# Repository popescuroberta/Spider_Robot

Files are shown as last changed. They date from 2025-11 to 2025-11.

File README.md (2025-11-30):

# 🕷️ Spider Robot – Assembly & Setup Guide

This repository contains the full instructions for assembling an Arduino-based spider robot with 8 servos, 3D-printed parts, and a DC-DC buck converter.  
Follow this guide carefully to ensure proper mechanical alignment and safe electrical wiring.

---

## 📦 Required Components

### Electronics
- Arduino Nano  
- Arduino Nano Expansion Shield  
- DC-DC Buck (Step-Down) Converter  
- 8 × SG90 / MG90 Servo Motors  
- Battery Pack

### Printed & Mechanical Parts
- Support Cross  
- Upper and Lower Servo Supports  
- Shoulder Elements (mirrored pairs)  
- Body Case and Top Plate  
- Claw Attachments  
- Printed Servo Support Caps

### Hardware
- M2 Nuts  
- M2 × 10 mm Screws  
- M2 × 8 mm Screws (for buck converter)  
- M3 Nuts  
- M3 × 6 mm Screws  
- M3 × 10 mm Screws  
- M3 Washers  
- Double-Sided Tape  
- Self-tapping screws (included with servos)

---

## 🛠️ Assembly Instructions

### 1. Assemble the Support Cross and Servo Shoulders
1. Insert **M2 nuts** into the grooves of the support cross.  
   - Align the nut with the screw hole.  
   - If needed, gently push the nut with a flat screwdriver.

2. Insert **M2 × 10 mm screws** through the servo support holes and tighten them into the nuts in the support cross.

3. Attach the remaining structural servo-support parts using **4 screws + 4 nuts (M2)**.

4. Assemble the **second shoulder as a mirrored version** of the first.  
   - Upper and lower supports must swap places in the mirrored part.

5. Assemble the second pair of shoulders similarly.  
   - You must end up with **two mirrored pairs**.

---

## 🔌 2. Connecting the Expansion Board & DC-DC Converter

You may solder these before or after mechanical assembly.

- Solder the buck converter **VOUT → 5V** and **GND → GND** to the expansion board.  
- Do **not** use standard male–female jumper wires (current ≈ 1A may overheat them).

### Wiring Polarity
- **Battery Pack → VIN & GND (buck input)**  
- **Expansion Board → VOUT & GND (buck output)**

After tightening terminal screws, lightly pull each wire to ensure it’s secure.

---

## 🧩 3. Installing the Printed Servo Supports

Using double-sided tape, attach each printed support to the *servo casing*:
- The cylindrical part of the support must be on the **shaft side**.
- Prepare all **8 servos** this way.

---

## 🎯 4. Servo Calibration (Zero Positioning)

All 8 servos must be set to **90°** before installation.

You can calibrate using:
- A servo tester, or  
- Calibration code on the Arduino.

### Servo wiring:
- **Red → 5V**  
- **Brown → GND**  
- **Orange → Signal**

Test any servo issues by trying a different signal pin.

Disconnect calibrated servos and set them aside.

---

## ⚙️ 5. Installing Servos Into the Shoulders

1. Insert calibrated servos into each shoulder assembly.  
2. If fitting is tight:
   - Loosen screws 1–2 mm.  
   - Retighten after the servo is fully inserted.

3. Test rotation of the cylindrical support inside the lower groove.  
   - If too stiff, rotate the joint several times to loosen it.

4. If the servo horn does not fully enter its slot:
   - Gently push it with pliers.

Use the **self-tapping screws** from the servo kit to secure horns and mounts.

---

## 🔋 6. Battery Compartment

Do **not** drill additional holes.  
Battery packs vary in shape and hole placement.

- Place the battery pack into the lower case, held by printed borders.  
- Use double-sided tape if needed.

---

## 🏗️ 7. Body Assembly & Electronics Placement

### Step 1 — Install Standoffs  
Use **M3 × 6 screws** and **M3 washers** to mount the standoffs to the body.

### Step 2 — Mount the Expansion Board  
Use:  
- **M3 × 10 screws**, **M3 nuts**, **M3 washers**  
- Mount using the two center holes (hard to access later).

### Step 3 — Mount the DC-DC Buck Converter  
Use:  
- **M2 × 8 screws**, washers, and M2 nuts

### Step 4 — Attach the Top Plate  
- **M3 × 10 screws** for holes below the expansion board  
- **M3 × 6 screws** for the other holes  
- Always place M3 washers on the plastic side.

Finally, insert the **Arduino Nano** into the expansion shield.

---

## 🕷️ 8. Final Assembly

- Insert the shoulder units into the case grooves.  
- Attach the claws to the servo shafts.  
- Secure all servo horns and claws using the included self-tapping screws.

---

## 🔗 9. Servo Port Mapping

- Shoulder servos → **Odd-numbered ports**  
- Claw servos → **Even-numbered ports**  
- Counting begins at the **4th pin**.

Orientation:
- **Front (head)** = side closer to the expansion board  
- **Tail** = side near the buck converter  
- Servos are numbered **clockwise** around the body.

---

## 🧪 10. Final Calibration (with Arduino Code)

Upload the calibration program:
- All servos return to a **zero position** at startup.  
- Check if all legs are perpendicular to the body.

If a leg is misaligned:
- Remove the servo horn  
- Reposition at 90°  
- Reattach

**Precision is important; even small errors affect walking performance.**

---

## ✔️ The Spider Robot Is Ready!

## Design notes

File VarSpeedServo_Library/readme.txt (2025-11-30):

To install the VarSpeedServo library in Arduino IDE, you need to follow these steps:
1. Download the .zip archive
2. After downloading, reopen Arduino IDE. In the menu Sketch -> Include library -> Add .zip library...
3. From the dialog box, select the archive you downloaded
4. To verify the functionality, restart Arduino IDE. Compile and upload a test code to an Arduino board. If there are no errors, everything is fine

Advantages of using the VarSpeedServo library:
1. Allows simultaneous use of up to 8 asynchronous servomotors
2. The speed of the servomotors can be set (an advantage, because we can avoid overloading the Arduino board)
3. Multiple commands can be sent simultaneously to the servomotor, without overloading it

Recommendation: move the library archive to the folder intended for the IDE application, so that, in case of deletion from the save folder, possible errors can be avoided.

https://github.com/netlabtoolkit/VarSpeedServo

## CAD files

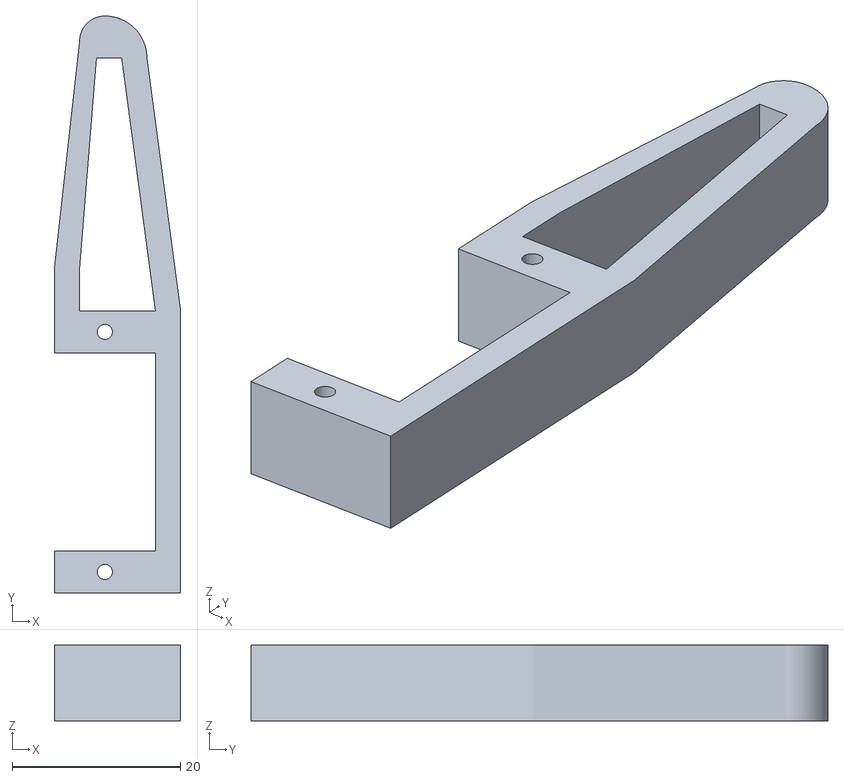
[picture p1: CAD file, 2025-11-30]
Files_For_Printing/Claw.stl
15.0 x 68.5 x 9.00

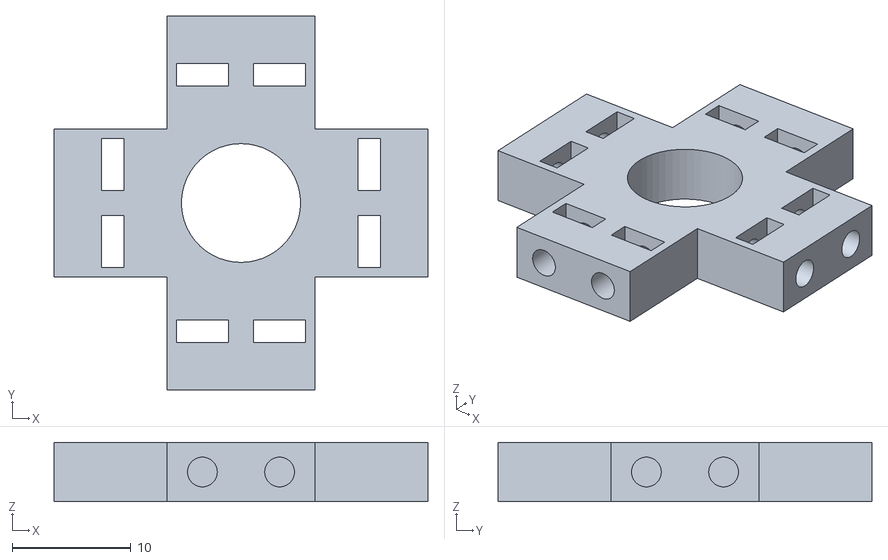
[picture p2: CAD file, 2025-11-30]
Files_For_Printing/Support cross.stl
31.5 x 31.5 x 5.00

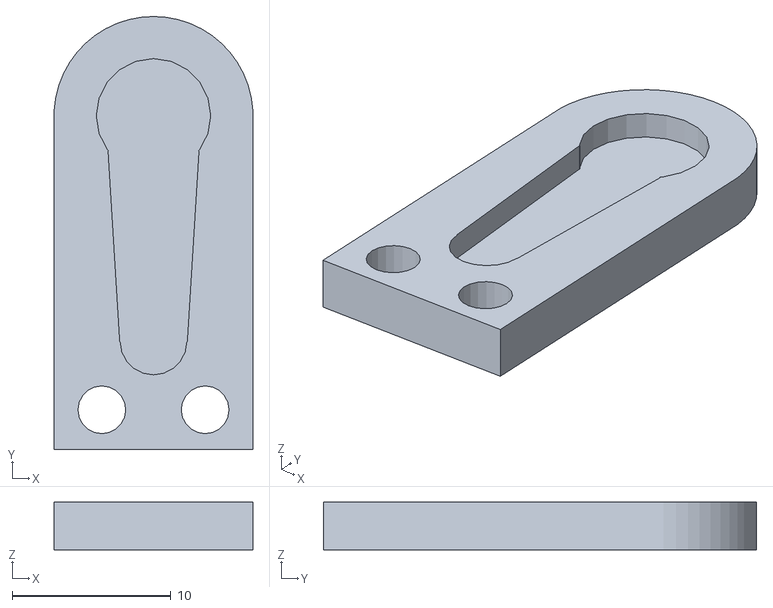
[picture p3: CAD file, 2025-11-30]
Files_For_Printing/Upper servo support.stl
12.5 x 27.2 x 3.00

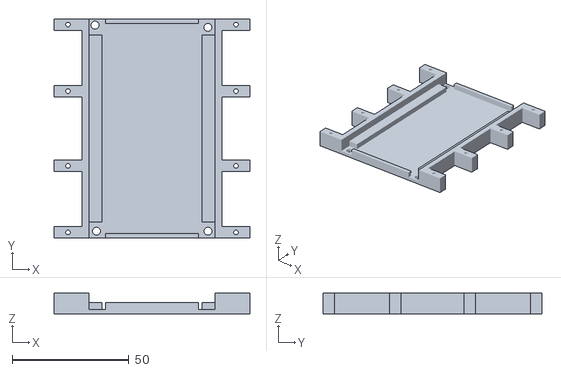
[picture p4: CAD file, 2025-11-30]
Files_For_Printing/Case (body).stl
84.0 x 94.0 x 9.00

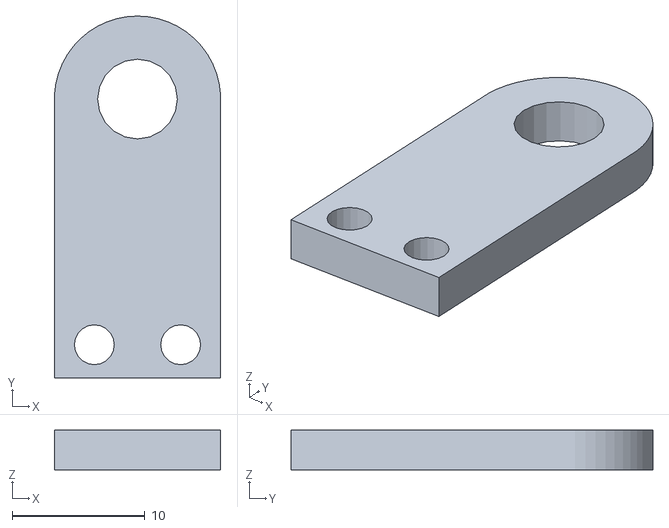
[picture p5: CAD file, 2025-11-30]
Files_For_Printing/Lower servo support.stl
12.5 x 27.2 x 3.00

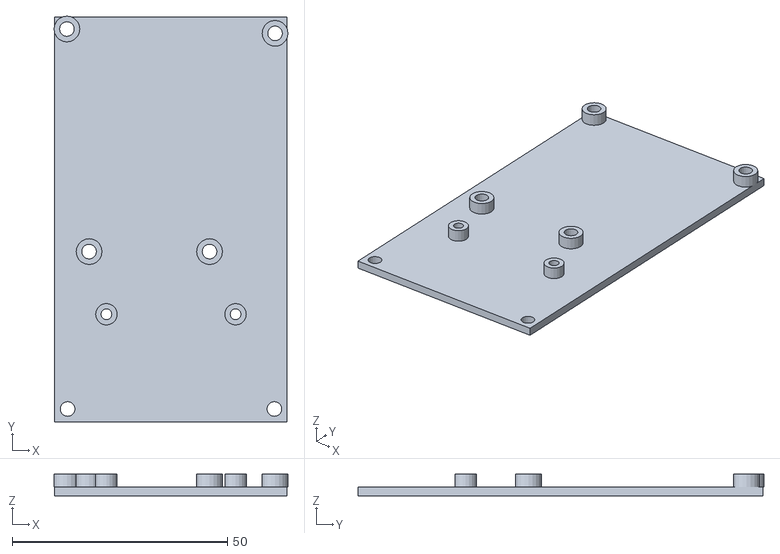
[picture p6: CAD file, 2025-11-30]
Files_For_Printing/Plate.stl
54.4 x 94.2 x 5.00

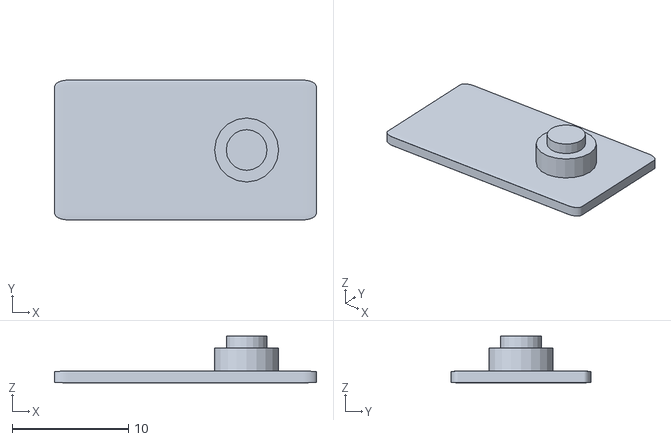
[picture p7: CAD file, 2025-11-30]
Files_For_Printing/Servo support.stl
22.5 x 12.0 x 4.00

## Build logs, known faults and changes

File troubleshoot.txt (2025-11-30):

A. The code does not work
Check the library used. If the VarSpeedServo library is used, in the Code folder, there is a readme with the steps to load the library

B. Although the motors were adjusted before assembly to 90 degrees, once assembled, they seem to go in the wrong direction
It is about the way the shoulder is attached. The shoulder where the clamp and the servo are attached to the body will be removed, and the shoulder components (the one with the incision for the servo arm and the one for rotating) can be reversed. Afterwards, check the servo motor again if it rotates in the correct direction. Most of the time, this operation solves the problem

C. The code does not load on my Arduino, although I have the library installed in the IDE
Most of the time, it is from the processor that the application has. In the Tools -> Processor -> ATmega 328P (Old Bootloader) tab, it will solve the problem. Chinese motherboards have, in 80% of cases, this processor

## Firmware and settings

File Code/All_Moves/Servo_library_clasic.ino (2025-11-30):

#include <Servo.h>

// Declarație servomotoare
Servo myServo4;
Servo myServo5;
Servo myServo6;
Servo myServo7;
Servo myServo8;
Servo myServo9;
Servo myServo10;
Servo myServo11;

void setup() {
  // Inițializare servomotoare
  myServo4.attach(4);
  myServo5.attach(5);
  myServo6.attach(6);
  myServo7.attach(7);
  myServo8.attach(8);
  myServo9.attach(9);
  myServo10.attach(10);
  myServo11.attach(11);
  
  // Pornire din poziția inițială
  startPosition();
  delay(5000); // Așteptare inițială
}

void loop() {
  // Secvență de mișcări
  walkForward();
  delay(1000);
  
  turnLeft();
  delay(1000);
  
  turnRight();
  delay(1000);
  
  dogAnimation();
  delay(1000);
  
  physicalExercise();
  delay(1000);
  
  legsLeftRight();
  delay(1000);
  
  legsInside();
  delay(1000);
  
  layStay();
  delay(1000);
  
  // Revenire la poziția inițială
  startPosition();
  delay(2000);
}

// ========== SEGMENT: Poziția inițială ==========
void startPosition() {
  myServo4.write(90);
  myServo5.write(90);
  myServo6.write(90);
  myServo7.write(90);
  myServo8.write(90);
  myServo9.write(90);
  myServo10.write(90);
  myServo11.write(90);
  delay(500);
}

// ========== SEGMENT: Mers înainte ==========
void walkForward() {
  // Configurare poziție de start pentru mers
  myServo5.write(45);
  myServo7.write(135);
  myServo9.write(45);
  myServo11.write(135);
  delay(1000);
  
  myServo10.write(115);
  myServo11.write(85);
  myServo5.write(95);
  delay(200);
  myServo10.write(90);

  // Ciclu de mers
  myServo8.write(50);
  delay(200);
  myServo11.write(135);
  myServo7.write(75);
  myServo9.write(90);
  myServo4.write(60);
  myServo5.write(45);
  myServo8.write(90);
  delay(200);
  myServo4.write(90);
  myServo10.write(130);
  delay(200);
  myServo9.write(45);
  myServo5.write(105);
  myServo11.write(90);
  myServo6.write(120);
  myServo7.write(135);
  myServo10.write(90);
  delay(200);
  myServo6.write(90);
}

// ========== SEGMENT: Viraj la stânga ==========
void turnLeft() {
  for (int count = 0; count < 5; count++) {
    myServo5.write(45);
    delay(500);
    myServo9.write(45);
    delay(500);
    myServo6.write(120);
    myServo7.write(180);
    delay(500);
    myServo6.write(90);
    delay(250);
    myServo10.write(120);
    myServo11.write(180);
    delay(250);
    myServo10.write(90);
    delay(500);
    myServo5.write(5);
    myServo7.write(135);
    myServo9.write(5);
    myServo11.write(135);
    delay(500);
  }
  
  // Revenire la poziția normală
  myServo5.write(90);
  myServo7.write(90);
  myServo9.write(90);
  myServo11.write(90);
}

// ========== SEGMENT: Viraj la dreapta ==========
void turnRight() {
  for (int count = 0; count < 5; count++) {
    myServo7.write(135);
    delay(500);
    myServo11.write(135);
    delay(500);
    myServo4.write(60);
    myServo5.write(0);
    delay(500);
    myServo4.write(90);
    delay(250);
    myServo8.write(60);
    myServo9.write(0);
    delay(250);
    myServo8.write(90);
    delay(500);
    myServo5.write(45);
    myServo7.write(175);
    myServo9.write(45);
    myServo11.write(175);
    delay(500);
  }
  
  // Revenire la poziția normală
  myServo5.write(90);
  myServo7.write(90);
  myServo9.write(90);
  myServo11.write(90);
}

// ========== SEGMENT: Animație câine ==========
void dogAnimation() {
  for (int count = 0; count < 3; count++) {
    myServo5.write(0);
    myServo7.write(180);
    myServo9.write(20);
    myServo11.write(160);
    delay(1000);
    
    myServo4.write(20);
    myServo6.write(160);
    delay(500);
    
    for (int innerCount = 0; innerCount < 3; innerCount++) {
      myServo9.write(40);
      myServo11.write(180);
      delay(500);
      myServo9.write(0);
      myServo11.write(140);
      delay(500);
    }
    
    myServo9.write(20);
    myServo11.write(160);
    myServo4.write(90);
    myServo6.write(90);
    delay(1000);
    
    myServo5.write(90);
    myServo7.write(90);
    myServo9.write(90);
    myServo11.write(90);
    delay(1000);
  }
}

// ========== SEGMENT: Exercițiu fizic ==========
void physicalExercise() {
  for (int count = 0; count < 3; count++) {
    myServo5.write(70);
    myServo7.write(110);
    myServo9.write(10);
    myServo11.write(170);
    delay(500);
    
    myServo8.write(20);
    myServo10.write(160);
    delay(1000);
    
    for (int innerCount = 0; innerCount < 3; innerCount++) {
      myServo4.write(30);
      myServo6.write(150);
      delay(500);
      myServo4.write(90);
      myServo6.write(90);
      delay(500);
    }
    
    myServo8.write(90);
    myServo10.write(90);
    delay(500);
    
    myServo5.write(90);
    myServo7.write(90);
    myServo9.write(90);
    myServo11.write(90);
    delay(1000);
  }
}

// ========== SEGMENT: Mișcări picioare stânga-dreapta ==========
void legsLeftRight() {
  for (int count = 0; count < 3; count++) {
    myServo4.write(70);
    myServo6.write(70);
    myServo8.write(110);
    myServo10.write(110);
    delay(1000);
    
    myServo4.write(90);
    myServo6.write(90);
    myServo8.write(90);
    myServo10.write(90);
    delay(1000);
    
    myServo4.write(110);
    myServo6.write(110);
    myServo8.write(70);
    myServo10.write(70);
    delay(1000);
    
    myServo4.write(90);
    myServo6.write(90);
    myServo8.write(90);
    myServo10.write(90);
    delay(1000);
  }
}

// ========== SEGMENT: Picioare în interior ==========
void legsInside() {
  for (int count = 0; count < 3; count++) {
    myServo4.write(110);
    myServo6.write(70);
    myServo8.write(110);
    myServo10.write(70);
    delay(1000);
    
    myServo4.write(90);
    myServo6.write(90);
    myServo8.write(90);
    myServo10.write(90);
    delay(1000);
  }
}

// ========== SEGMENT: Culcare și stat ==========
void layStay() {
  for (int count = 0; count < 3; count++) {
    myServo4.write(0);
    myServo6.write(180);
    myServo8.write(0);
    myServo10.write(180);
    delay(1000);
    
    myServo4.write(90);
    myServo6.write(90);
    myServo8.write(90);
    myServo10.write(90);
    delay(1000);
  }
}

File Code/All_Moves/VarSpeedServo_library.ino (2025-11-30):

#include <VarSpeedServo.h>

// Declarație servomotoare
VarSpeedServo myServo4;
VarSpeedServo myServo5;
VarSpeedServo myServo6;
VarSpeedServo myServo7;
VarSpeedServo myServo8;
VarSpeedServo myServo9;
VarSpeedServo myServo10;
VarSpeedServo myServo11;

void setup() {
  // Inițializare servomotoare
  myServo4.attach(4);
  myServo5.attach(5);
  myServo6.attach(6);
  myServo7.attach(7);
  myServo8.attach(8);
  myServo9.attach(9);
  myServo10.attach(10);
  myServo11.attach(11);
  
  // Pornire din poziția inițială
  startPosition();
  delay(5000); // Așteptare inițială
}

void loop() {
  // Secvență de mișcări
  walkForward();
  delay(1000);
  
  turnLeft();
  delay(1000);
  
  turnRight();
  delay(1000);
  
  dogAnimation();
  delay(1000);
  
  physicalExercise();
  delay(1000);
  
  legsLeftRight();
  delay(1000);
  
  legsInside();
  delay(1000);
  
  layStay();
  delay(1000);
  
  // Revenire la poziția inițială
  startPosition();
  delay(2000);
}

// ========== SEGMENT: Poziția inițială ==========
void startPosition() {
  myServo4.slowmove(90, 255);
  myServo5.slowmove(90, 255);
  myServo6.slowmove(90, 255);
  myServo7.slowmove(90, 255);
  myServo8.slowmove(90, 255);
  myServo9.slowmove(90, 255);
  myServo10.slowmove(90, 255);
  myServo11.slowmove(90, 255);
  delay(500);
}

// ========== SEGMENT: Mers înainte ==========
void walkForward() {
  // Configurare poziție de start pentru mers
  myServo5.slowmove(45, 255);
  myServo7.slowmove(135, 255);
  myServo9.slowmove(45, 255);
  myServo11.slowmove(135, 255);
  delay(1000);
  
  myServo10.slowmove(115, 255);
  myServo11.slowmove(85, 255);
  myServo5.slowmove(95, 255);
  delay(200);
  myServo10.slowmove(90, 255);

  // Ciclu de mers
  myServo8.slowmove(50, 255);
  delay(200);
  myServo11.slowmove(135, 255);
  myServo7.slowmove(75, 255);
  myServo9.slowmove(90, 255);
  myServo4.slowmove(60, 255);
  myServo5.slowmove(45, 255);
  myServo8.slowmove(90, 255);
  delay(200);
  myServo4.slowmove(90, 255);
  myServo10.slowmove(130, 255);
  delay(200);
  myServo9.slowmove(45, 255);
  myServo5.slowmove(105, 255);
  myServo11.slowmove(90, 255);
  myServo6.slowmove(120, 255);
  myServo7.slowmove(135, 255);
  myServo10.slowmove(90, 255);
  delay(200);
  myServo6.slowmove(90, 255);
}

// ========== SEGMENT: Viraj la stânga ==========
void turnLeft() {
  for (int count = 0; count < 5; count++) {
    myServo5.slowmove(45, 255);
    delay(500);
    myServo9.slowmove(45, 255);
    delay(500);
    myServo6.slowmove(120, 255);
    myServo7.slowmove(180, 255);
    delay(500);
    myServo6.slowmove(90, 255);
    delay(250);
    myServo10.slowmove(120, 255);
    myServo11.slowmove(180, 255);
    delay(250);
    myServo10.slowmove(90, 255);
    delay(500);
    myServo5.slowmove(5, 50);
    myServo7.slowmove(135, 50);
    myServo9.slowmove(5, 50);
    myServo11.slowmove(135, 50);
    delay(500);
  }
  
  // Revenire la poziția normală
  myServo5.slowmove(90, 50);
  myServo7.slowmove(90, 50);
  myServo9.slowmove(90, 50);
  myServo11.slowmove(90, 50);
}

// ========== SEGMENT: Viraj la dreapta ==========
void turnRight() {
  for (int count = 0; count < 5; count++) {
    myServo7.slowmove(135, 255);
    delay(500);
    myServo11.slowmove(135, 255);
    delay(500);
    myServo4.slowmove(60, 255);
    myServo5.slowmove(0, 255);
    delay(500);
    myServo4.slowmove(90, 255);
    delay(250);
    myServo8.slowmove(60, 255);
    myServo9.slowmove(0, 255);
    delay(250);
    myServo8.slowmove(90, 255);
    delay(500);
    myServo5.slowmove(45, 50);
    myServo7.slowmove(175, 50);
    myServo9.slowmove(45, 50);
    myServo11.slowmove(175, 50);
    delay(500);
  }
  
  // Revenire la poziția normală
  myServo5.slowmove(90, 50);
  myServo7.slowmove(90, 50);
  myServo9.slowmove(90, 50);
  myServo11.slowmove(90, 50);
}

// ========== SEGMENT: Animație câine ==========
void dogAnimation() {
  for (int count = 0; count < 3; count++) {
    myServo5.slowmove(0, 255);
    myServo7.slowmove(180, 255);
    myServo9.slowmove(20, 255);
    myServo11.slowmove(160, 255);
    delay(1000);
    
    myServo4.slowmove(20, 255);
    myServo6.slowmove(160, 255);
    delay(500);
    
    for (int innerCount = 0; innerCount < 3; innerCount++) {
      myServo9.slowmove(40, 255);
      myServo11.slowmove(180, 255);
      delay(500);
      myServo9.slowmove(0, 255);
      myServo11.slowmove(140, 255);
      delay(500);
    }
    
    myServo9.slowmove(20, 255);
    myServo11.slowmove(160, 255);
    myServo4.slowmove(90, 255);
    myServo6.slowmove(90, 255);
    delay(1000);
    
    myServo5.slowmove(90, 255);
    myServo7.slowmove(90, 255);
    myServo9.slowmove(90, 255);
    myServo11.slowmove(90, 255);
    delay(1000);
  }
}

// ========== SEGMENT: Exercițiu fizic ==========
void physicalExercise() {
  for (int count = 0; count < 3; count++) {
    myServo5.slowmove(70, 255);
    myServo7.slowmove(110, 255);
    myServo9.slowmove(10, 255);
    myServo11.slowmove(170, 255);
    delay(500);
    
    myServo8.slowmove(20, 255);
    myServo10.slowmove(160, 255);
    delay(1000);
    
    for (int innerCount = 0; innerCount < 3; innerCount++) {
      myServo4.slowmove(30, 150);
      myServo6.slowmove(150, 150);
      delay(500);
      myServo4.slowmove(90, 150);
      myServo6.slowmove(90, 150);
      delay(500);
    }
    
    myServo8.slowmove(90, 255);
    myServo10.slowmove(90, 255);
    delay(500);
    
    myServo5.slowmove(90, 255);
    myServo7.slowmove(90, 255);
    myServo9.slowmove(90, 255);
    myServo11.slowmove(90, 255);
    delay(1000);
  }
}

// ========== SEGMENT: Mișcări picioare stânga-dreapta ==========
void legsLeftRight() {
  for (int count = 0; count < 3; count++) {
    myServo4.slowmove(70, 255);
    myServo6.slowmove(70, 255);
    myServo8.slowmove(110, 255);
    myServo10.slowmove(110, 255);
    delay(1000);
    
    myServo4.slowmove(90, 255);
    myServo6.slowmove(90, 255);
    myServo8.slowmove(90, 255);
    myServo10.slowmove(90, 255);
    delay(1000);
    
    myServo4.slowmove(110, 255);
    myServo6.slowmove(110, 255);
    myServo8.slowmove(70, 255);
    myServo10.slowmove(70, 255);
    delay(1000);
    
    myServo4.slowmove(90, 255);
    myServo6.slowmove(90, 255);
    myServo8.slowmove(90, 255);
    myServo10.slowmove(90, 255);
    delay(1000);
  }
}

// ========== SEGMENT: Picioare în interior ==========
void legsInside() {
  for (int count = 0; count < 3; count++) {
    myServo4.slowmove(110, 255);
    myServo6.slowmove(70, 255);
    myServo8.slowmove(110, 255);
    myServo10.slowmove(70, 255);
    delay(1000);
    
    myServo4.slowmove(90, 255);
    myServo6.slowmove(90, 255);
    myServo8.slowmove(90, 255);
    myServo10.slowmove(90, 255);
    delay(1000);
  }
}
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
